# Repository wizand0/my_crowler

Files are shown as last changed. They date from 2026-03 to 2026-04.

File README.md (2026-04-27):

# 🔦 Crawler Inspector — Робот-телеинспектор вентиляции

> **Самодельный автономный краулер для осмотра вентиляционных каналов**  
> Платформа T101 · ESP32-CAM · Arduino UNO R3 · Wi-Fi управление · Автопилот · Запись видео · Лог маршрута






---

## 📸 Фотографии устройства

| | | |
|:---:|:---:|:---:|
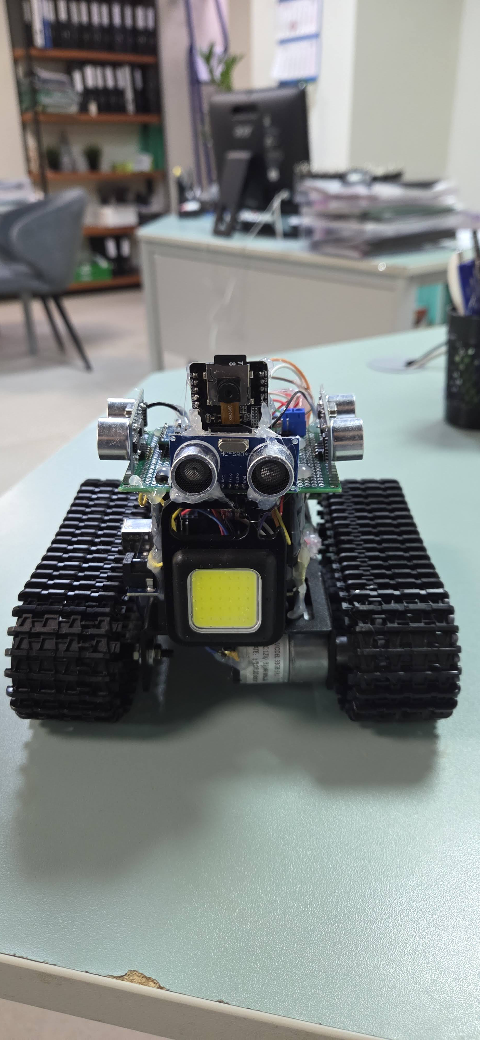
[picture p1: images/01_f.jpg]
Вид спереди
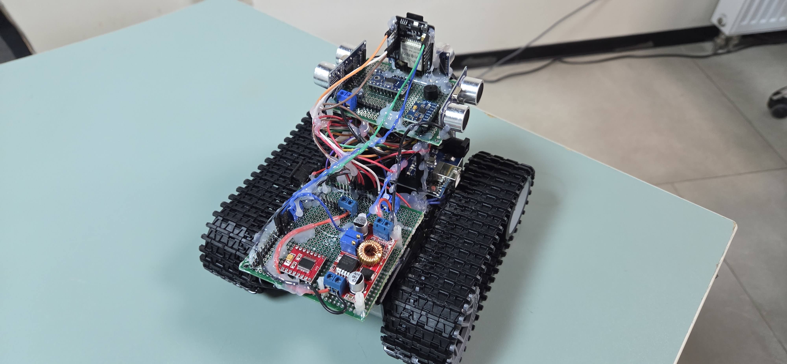
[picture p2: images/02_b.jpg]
Вид сзади
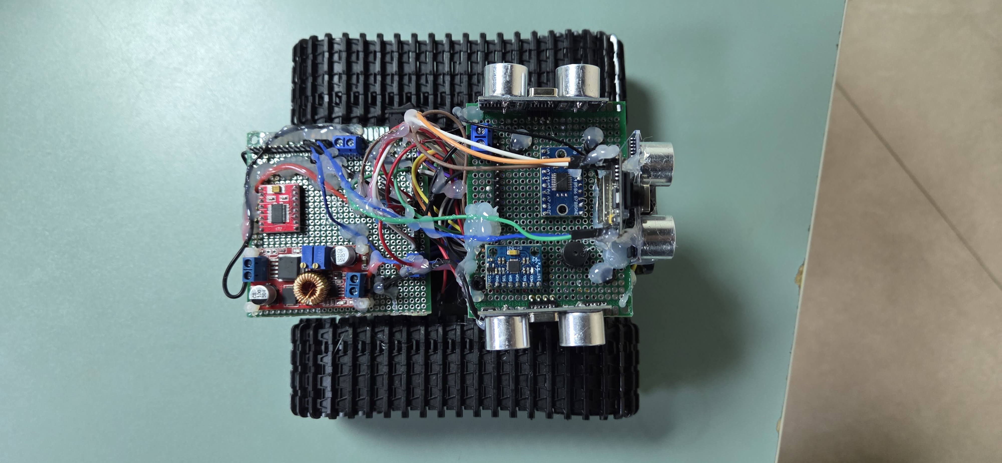
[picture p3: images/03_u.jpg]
Вид сверху
|  |  |  |
| *Вид спереди* | *Вид сзади* | *Вид сверху* |
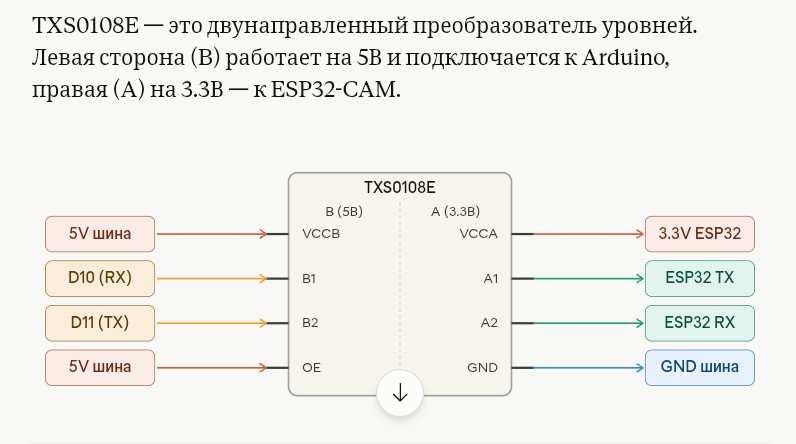
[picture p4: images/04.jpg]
Вид снизу
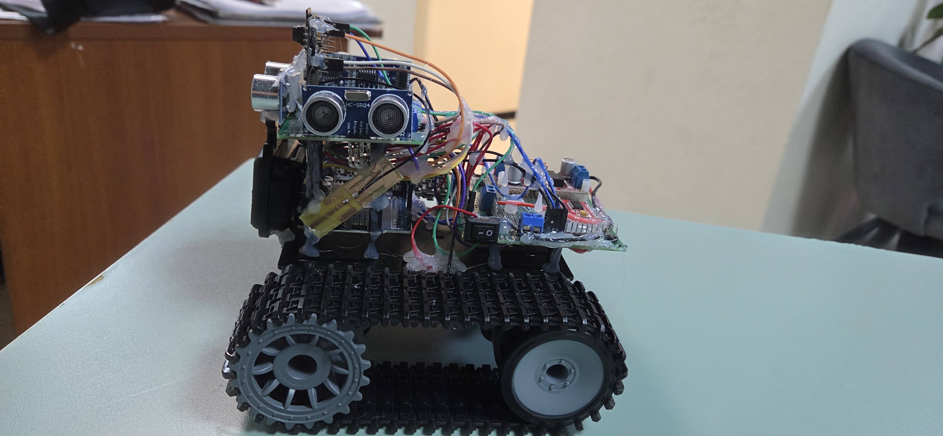
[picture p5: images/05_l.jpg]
Левый борт
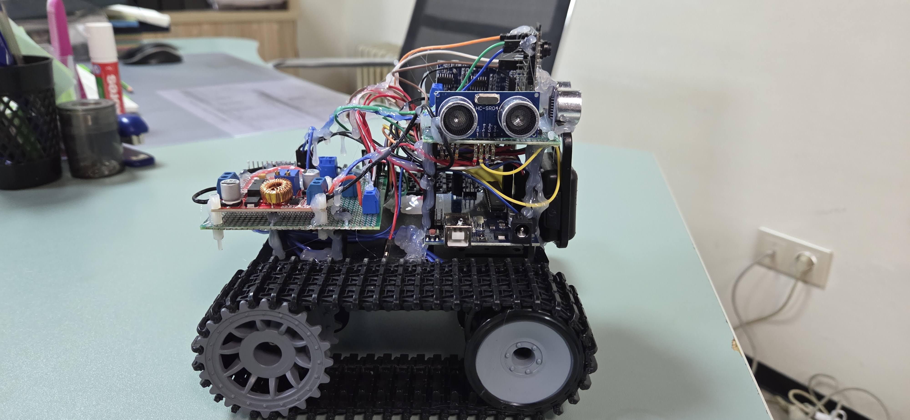
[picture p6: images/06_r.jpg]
Правый борт
|  |  |  |
| *Вид снизу* | *Левый борт* | *Правый борт* |
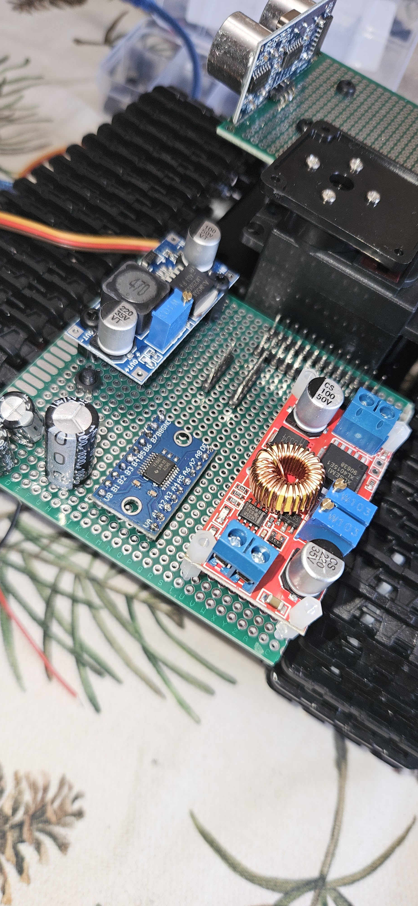
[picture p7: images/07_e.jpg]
Электроника
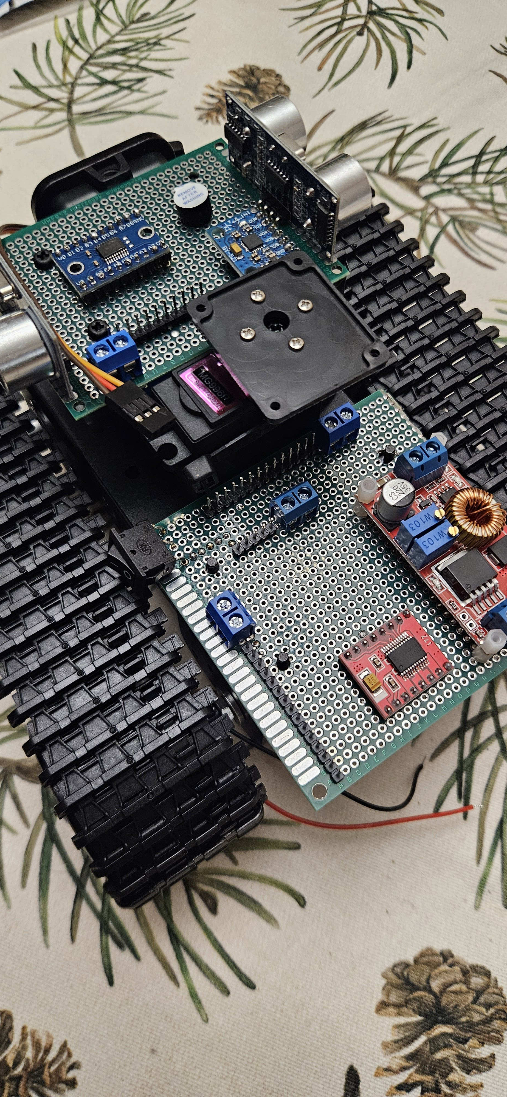
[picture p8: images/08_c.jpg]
Камера и серво
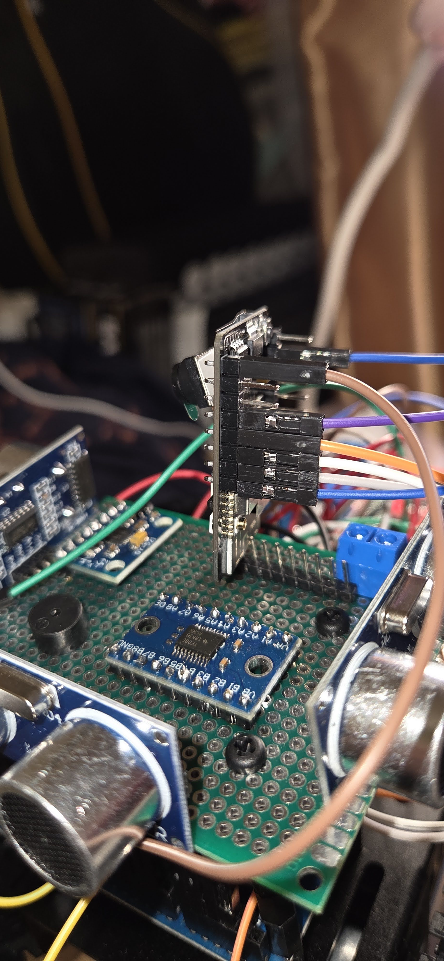
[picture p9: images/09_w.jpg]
В работе
|  |  |  |
| *Электроника* | *Камера и серво* | *В работе* |

---

## 📋 Содержание

1. [О проекте](#о-проекте)
2. [Архитектура системы](#архитектура-системы)
3. [Список компонентов](#список-компонентов)
4. [Схема подключений](#схема-подключений)
5. [Сборка шасси Mini T101](#сборка-шасси-mini-t101)
6. [Монтаж электроники](#монтаж-электроники)
7. [Пайка и коммутация](#пайка-и-коммутация)
8. [Загрузка прошивки](#загрузка-прошивки)
9. [Калибровка](#калибровка)
10. [Первое включение и тестирование](#первое-включение-и-тестирование)
11. [Веб-интерфейс управления](#веб-интерфейс-управления)
12. [Автопилот и конечный автомат](#автопилот-и-конечный-автомат)
13. [Защита от спуска](#защита-от-спуска)
14. [Одометрия и лог маршрута CSV](#одометрия-и-лог-маршрута-csv)
15. [Конвертация записи в видео](#конвертация-записи-в-видео)
16. [Зуммер-сигнализация](#зуммер-сигнализация)
17. [Описание прошивки Arduino](#описание-прошивки-arduino)
18. [Описание прошивки ESP32-CAM](#описание-прошивки-esp32-cam)
19. [Диагностика неисправностей](#диагностика-неисправностей)
20. [Конфигурационные параметры](#конфигурационные-параметры)
21. [Структура репозитория](#структура-репозитория)
22. [Зависимости и библиотеки](#зависимости-и-библиотеки)
23. [История версий (CHANGELOG)](#история-версий-changelog)
24. [Лицензия и вклад в проект](#лицензия-и-вклад-в-проект)

---

## 🤖 О проекте

**Crawler Inspector** — это самодельный робот-телеинспектор, предназначенный для видеоосмотра вентиляционных каналов и других труднодоступных пространств. Основная задача — заменить ручную инспекцию вентиляции в жилых и промышленных зданиях без дорогостоящего профессионального оборудования.

Оператор управляет роботом через браузер (смартфон или ноутбук) по Wi-Fi, видя прямую трансляцию с камеры. При потере сигнала или нажатии AUTO робот самостоятельно продолжает движение до 20 минут, логируя маршрут в CSV-файл. На конце страховочного троса оператор физически вытягивает краулер.

### Ключевые возможности v2.0

| Возможность | Описание |
|---|---|
| **Wi-Fi управление** | Браузерный интерфейс с джойстиком, работает на смартфоне и ноутбуке |
| **MJPEG видеопоток** | Прямая трансляция с камеры OV2640 (320×240 или 640×480) |
| **Автономный автопилот** | Автоматическая езда по коридору с огибанием препятствий |
| **PTZ-камера** | Поворот камеры 45–135° сервоприводом MG996R |
| **Запись на SD** | Автостарт сохранения JPEG-кадров (5 fps) при включении |
| **Защита от спуска** | Обнаружение наклона >30° через MPU6050, аварийная остановка |
| **Лог маршрута CSV** | Одометрия, накопленное рыскание, события, показания датчиков |
| **Зуммер-сигнализация** | Паттерны SOS, BEACON, CRAWL, ABANDONED для разных ситуаций |
| **JSON /status API** | Эндпоинт статуса для внешних систем мониторинга |

### Сценарий применения

Краулер предназначен для работы с крыш и верхних точек зданий, где вентиляционные каналы уходят вниз. Оператор управляет роботом вручную, пока есть Wi-Fi сигнал (обычно 3–4 метра в металлическом коробе), затем робот автоматически переходит в режим автопилота и продолжает движение самостоятельно. По окончании маршрута или при обнаружении тупика / спуска подаётся сигнал зуммером. Оператор вытягивает робота за страховочный трос, прикреплённый к шасси. На SD-карте остаются видеокадры и CSV-лог с картой маршрута.

---

## 🏗 Архитектура системы

```
╔══════════════════════════════════════════════════════════════════════════╗
║                          CRAWLER INSPECTOR v2.0                          ║
║                                                                          ║
║  ┌──────────────────────┐  UART 9600 бод  ┌──────────────────────────┐   ║
║  │    ESP32-CAM          │◄──────────────►│    Arduino UNO R3        │   ║
║  │    (Master)           │   TXS0108E     │    (Slave)               │   ║
║  │                       │   3.3V ↔ 5V    │                          │   ║
║  │  • Wi-Fi AP           │                │  • TB6612FNG (моторы)    │   ║
║  │  • Веб-сервер :80    │ F,B,L,R,S,P,H   │  • HC-SR04 × 3           │   ║
║  │  • MJPEG :81         │◄───────────────►│  • MPU6050 (pitch+yaw)   │   ║
║  │  • SD-карта (запись) │  LOG:EVT,...    │  • Servo MG996R          │   ║
║  │  • CSV лог маршрута  │  REC_AUTO       │  • Зуммер                │   ║
║  └──────────────────────┘                 └──────────────────────────┘   ║
╚══════════════════════════════════════════════════════════════════════════╝
```

**Ролевое разделение:**

- **ESP32-CAM (Master)** — управляет Wi-Fi, стримингом видео, записью на SD, CSV-логом маршрута. Отправляет команды на Arduino и принимает LOG-строки.
- **Arduino UNO (Slave)** — управляет моторами, ультразвуковыми датчиками, IMU, сервоприводом и зуммером. Выполняет всю логику конечного автомата.

---

## 🛒 Список компонентов

| Компонент | Кол-во | Назначение |
|---|:---:|---|
| Шасси Mini T101 (гусеничное) | 1 | Платформа робота |
| ESP32-CAM AI-Thinker | 1 | Мастер: Wi-Fi, камера, SD |
| Arduino UNO R3 | 1 | Слейв: управление периферией |
| TB6612FNG (модуль) | 1 | Драйвер двух моторов |
| Моторы 33GB-520 (под T101) | 2 | Привод гусениц |
| HC-SR04 | 3 | УЗ-дальномеры (перед, лево, право) |
| MPU6050 | 1 | Акселерометр + гироскоп (pitch/yaw) |
| Servo MG996R | 1 | Поворот камеры 0–180° |
| TXS0108E (модуль) | 1 | Согласование уровней 3.3V / 5V |
| MicroSD-карта FAT32 (≤32 ГБ) | 1 | Запись JPEG + CSV лог |
| Преобразователь XL4015 | 1 | Step-down до 5.0 В |
| Аккумулятор LiPo 2S (или 3S) | 1 | Питание |
| Зуммер пассивный 5 В | 1 | Звуковая сигнализация |
| MB-плата для ESP32-CAM | 1 | Загрузка прошивки |
| Нейлоновые стойки M3 | 8 | Крепление плат |
| Страховочный трос | 1 | Извлечение робота (обязательно!) |

---

## 🔌 Схема подключений

### Arduino UNO R3 (актуальная распиновка v2.0)

> ⚠️ В коде v2.0 распиновка моторов **изменена** относительно заголовочного комментария. Актуальные значения из `#define`:

| Пин Arduino | Функция | Комментарий |
|---|---|---|
| **D2** | Servo MG996R (сигнал) | Поворот камеры |
| **D3** | TB6612 BIN2 (мотор B) | |
| **D4** | TB6612 BIN1 (мотор B) | |
| **D5** | TB6612 PWMB (мотор B) | ШИМ правого мотора |
| **D6** | TB6612 PWMA (мотор A) | ШИМ левого мотора |
| **D7** | TB6612 AIN1 (мотор A) | |
| **D8** | TB6612 AIN2 (мотор A) | |
| **D9** | Зуммер (пассивный) | `tone()` 2000 Гц |
| **D10** | SoftwareSerial RX ← TXS0108E | Приём от ESP32 |
| **D11** | SoftwareSerial TX → TXS0108E | Отправка на ESP32 |
| **D12** | HC-SR04 RIGHT TRIG | УЗ правый |
| **D13** | HC-SR04 RIGHT ECHO | УЗ правый |
| **A0** | HC-SR04 FRONT TRIG | УЗ передний |
| **A1** | HC-SR04 FRONT ECHO | УЗ передний |
| **A2** | HC-SR04 LEFT TRIG | УЗ левый |
| **A3** | HC-SR04 LEFT ECHO | УЗ левый |
| **A4 (SDA)** | MPU6050 SDA | I2C, адрес 0x68 |
| **A5 (SCL)** | MPU6050 SCL | I2C |
| **5V** | TB6612 STBY | Всегда включён |

### ESP32-CAM (UART к TXS0108E)

| ESP32-CAM GPIO | Направление | TXS0108E | Arduino |
|---|---|---|---|
| GPIO1 (TX0) | → | A1 → B1 | D10 (RX) |
| GPIO3 (RX0) | ← | A2 ← B2 | D11 (TX) |
| 3.3V | | VCCA + OE | |
| GND | | GND | GND |

> **Питание TXS0108E:** VCCA = 3.3V (от ESP32), VCCB = 5V (от Arduino), OE = 3.3V.

### Схемы пайки

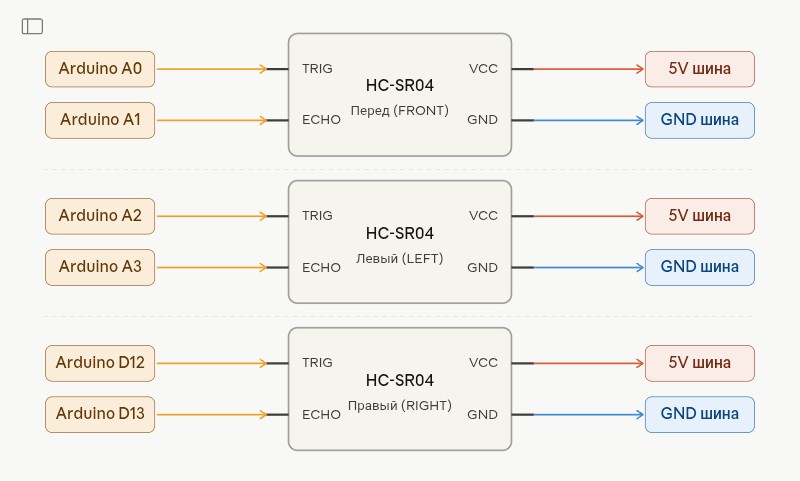
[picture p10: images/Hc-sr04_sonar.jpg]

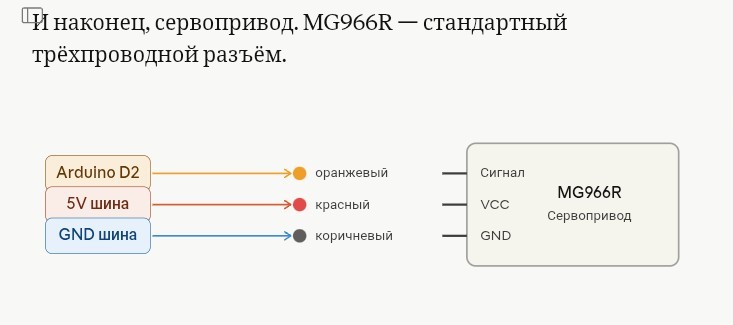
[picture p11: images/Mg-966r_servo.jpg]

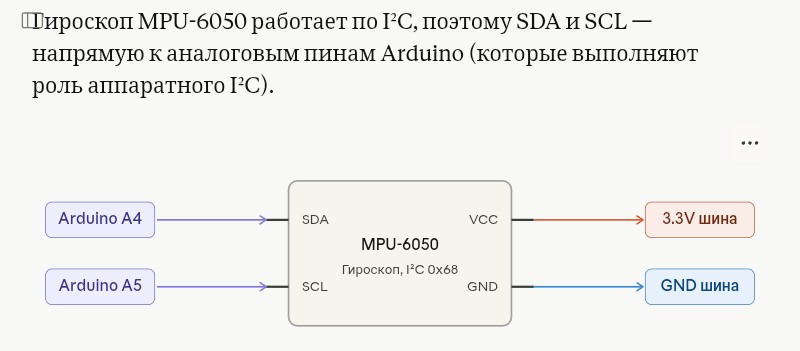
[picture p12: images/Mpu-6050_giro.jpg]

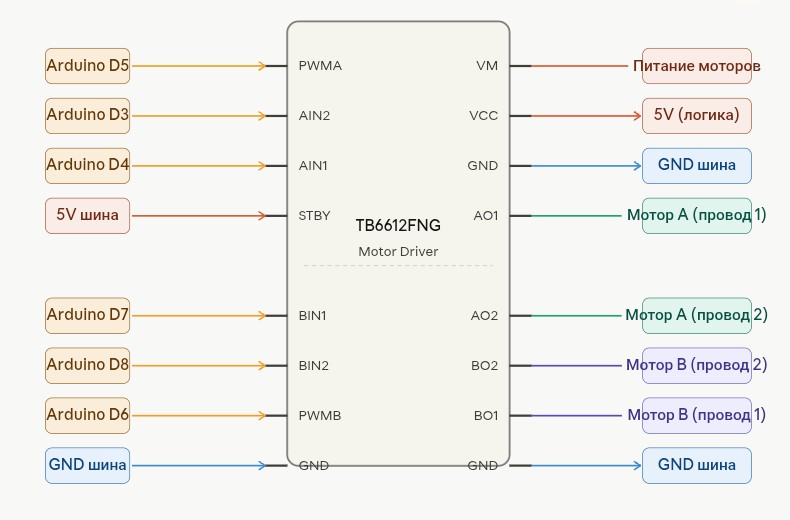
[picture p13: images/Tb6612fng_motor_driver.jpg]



---

## 🔧 Сборка шасси Mini T101

1. Собери шасси T101 с моторами 33GB-520 по инструкции производителя
2. Установи нейлоновые стойки M3 на монтажную плату
3. Закрепи TB6612FNG на стойках над корпусом
4. Размести Arduino UNO под основной платой
5. Установи ESP32-CAM на сервоплатформу спереди
6. Закрепи MG996R для поворота камеры (угол 45–135°)
7. Прикрути три HC-SR04: спереди по центру, слева, справа
8. Закрепи MPU6050 горизонтально по оси движения робота

---

## ⚡ Монтаж электроники

1. Настрой XL4015 на выходное напряжение **5.00 В** мультиметром до подключения нагрузки
2. Припаяй шины питания: 5V и GND на монтажной плате
3. Подключи TB6612FNG к Arduino согласно таблице выше
4. Подключи TXS0108E между ESP32 и Arduino
5. Подключи три HC-SR04 к Arduino
6. Подключи MPU6050 по I2C (A4/A5)
7. Подключи серво MG996R к D2 и 5V
8. Подключи зуммер к D9 и GND
9. Вставь SD-карту (FAT32, ≤32 ГБ) в ESP32-CAM

---

## 🛠 Загрузка прошивки

### Arduino UNO

```
1. Открой Arduino_UNO_Slave_v5.ino в Arduino IDE
2. Плата: Tools → Board → Arduino UNO
3. Порт: выбери COM-порт Arduino
4. Загрузи (Ctrl+U)
```

### ESP32-CAM

> ⚠️ **После загрузки через MB-плату: отключи USB-кабель перед подключением Arduino к UART. Иначе Arduino будет принимать USB-мусор вместо команд.**

```
1. Открой ESP32_CAM_Master_v5.ino в Arduino IDE
2. Установи пакет: Tools → Board Manager → "ESP32 by Espressif Systems" ≥ 2.0
3. Плата: AI-Thinker ESP32-CAM
4. Подключи MB-плату, переведи ESP32 в режим загрузки (IO0 → GND)
5. Загрузи, затем нажми кнопку Reset на ESP32-CAM
6. Отключи USB-кабель MB-платы
7. Подключи провода UART к Arduino
```

---

## 📐 Калибровка

### SPEED_MPS — одометрия (обязательно!)

Скорость `SPEED_MPS` используется для расчёта пройденного расстояния в одометрии и CSV-логе маршрута. Некалиброванное значение даст неточный лог.

```
1. Поставь краулер на ровную поверхность
2. Отметь стартовую точку маркером
3. Включи питание, подключись к Wi-Fi Crawler_Inspector
4. Нажми F (вперёд) и засеки точное время до 1 метра
5. SPEED_MPS = 1.0 / время_в_секундах
   Пример: проехал 1 м за 4.0 с → SPEED_MPS = 0.25f  (уже настроено)
6. Обнови значение в Arduino_UNO_Slave_v5.ino и перезагрузи
```

### Балансировка моторов

Если робот ведёт в сторону при движении вперёд, откорректируй масштаб мотора:

```cpp
#define MOTOR_L_SCALE   1.00f   // левый мотор (не трогать)
#define MOTOR_R_SCALE   0.90f   // уменьши, если правый быстрее
```

---

## ▶️ Первое включение и тестирование

```
1. Вставь SD-карту (FAT32, ≤32 ГБ) в ESP32-CAM
2. Прикрепи страховочный трос к шасси (обязательно!)
3. Включи питание — зуммер даст 2 пика (самотест OK)
4. Подожди 3–4 секунды инициализации
5. Подключись к Wi-Fi: "Crawler_Inspector" / "crawler123"
6. Открой браузер: http://192.168.4.1
7. Убедись что видеопоток запустился (статус 🟢 Видео: ОК)
8. Проверь что надпись "● REC" мигает (автозапись активна)
9. Протестируй движение джойстиком в ручном режиме
10. Откалибруй SPEED_MPS по реальному замеру (см. выше)
```

---

## 🌐 Веб-интерфейс управления

**Адрес:** `http://192.168.4.1` (порт 80)  
**Видеопоток:** `http://192.168.4.1:81/stream` (MJPEG)

### Элементы интерфейса

| Элемент | Функция |
|---|---|
| Видеоокно | MJPEG-поток с камеры OV2640 |
| Джойстик (canvas) | Управление направлением: F / B / L / R / S |
| Слайдер камеры | Поворот сервопривода 0–180° (команда `P<угол>`) |
| Кнопка ● REC | Ручное включение/выключение записи на SD |
| Кнопка AUTO | Включить/выключить режим автопилота |
| Статус | Текущее состояние: MANUAL / AUTO / REC_AUTO / AUTO_NO_WIFI |
| Пинг | Время отклика до ESP32 |
| Лог маршрута | Последняя строка из route_log.csv |

### HTTP API

| Метод | Путь | Параметры | Описание |
|---|---|---|---|
| GET | `/` | — | Главная страница (HTML/JS) |
| GET | `/cmd` | `m=F/B/L/R/S` или `p=<0-180>` | Команда мотора или угол серво |
| GET | `/rec` | `start=1/0` | Вкл/выкл запись на SD |
| GET | `/ping` | — | Ответ `pong` |
| GET | `/status` | — | JSON: состояние, последний лог |
| POST | `/auto` | `{"auto":true/false}` | Вкл/выкл автопилот |

#### Пример `/status` ответа

```json
{
  "status": "AUTO",
  "recording": true,
  "sd_ok": true,
  "session": "/REC_3",
  "last_log": "LOG:CHK,142,15,8,45,210,38",
  "clients": 1
}
```

---

## 🤖 Автопилот и конечный автомат

Автопилот включается автоматически при:
- Нажатии кнопки **AUTO** в интерфейсе
- Потере Wi-Fi клиента (нет heartbeat > 3 секунд)
- Приходе команды `'A'` от ESP32 (клиент отключился)

Максимальное время автономной миссии: **20 минут** (AUTO_MISSION_TIME).

### Состояния конечного автомата

```
                    ┌─────────────────────────────┐
                    │          ST_MANUAL          │
                    │  (оператор управляет)       │
                    └───────────────┬─────────────┘
                   AUTO / потеря HB │
                                    ▼
                    ┌──────────────────────────────┐
              ┌────►│        ST_AUTO_FWD           │◄───────┐
              │     │  едем вперёд, объезжаем      │        │
              │     └──┬──────────────┬────────────┘        │
              │     нет│ места        │тупик                │
              │        ▼              ▼                     │
              │  ┌─────────────┐  ┌─────────────┐           │
              │  │ST_AUTO_     │  │ ST_AUTO_    │           │
              │  │REVERSE      │  │ DEAD        │           │
              │  │(реверс 350мс│  │(зуммер SOS) │           │
              │  └──────┬──────┘  └─────────────┘           │
              │         ▼                                   │
              │  ┌──────────────────────────────┐           │
              └──┤        ST_AUTO_TURN          ├───────────┘
                 │  (поворот влево / вправо)    │
                 └──────────────────────────────┘
                              │ наклон > 30°
                              ▼
                 ┌────────────────────────────────┐
                 │        ST_TILT_PAUSE           │
                 │  (стоп, зуммер 8 сек)          │
                 └───────────────┬────────────────┘
                                 │ попытка движения
                                 ▼
                 ┌────────────────────────────────┐
                 │      ST_TILT_TRY_MOVE          │
                 │  (900 мс, скорость 65)         │
                 └────────────────────────────────┘
```

### Параметры автопилота

| Параметр | Значение | Описание |
|---|---|---|
| `SPEED_AUTO` | 55 | Базовая скорость в автопилоте |
| `SPEED_AUTO_MIN` | 42 | Минимум в тесных местах |
| `SPEED_AUTO_MAX` | 95 | Максимум на свободном участке |
| `DIST_FRONT_STOP` | 15 см | Стоп и разворот |
| `DIST_FRONT_CLEAR` | 24 см | Путь свободен |
| `DIST_SIDE_DEAD` | 12 см | Опасное сближение со стенкой |
| `DIST_SIDE_WARN` | 18 см | Предупреждение, корректировка курса |
| `TURN_FAIL_LIMIT` | 5 | Неудачных разворотов подряд → тупик |
| `OBSTACLE_MEMORY_MS` | 12000 мс | Окно памяти одного препятствия |
| `REVERSE_BEFORE_TURN_MS` | 350 мс | Реверс перед разворотом |

---

## ⛰ Защита от спуска

**Абсолютный приоритет** — выполняется первой в каждом цикле loop при любом состоянии кроме ST_MANUAL.

```
pitch < -30°  →  ST_TILT_PAUSE (стоп + непрерывный зуммер, 8 сек)
                 → ST_TILT_TRY_MOVE (попытка выехать, 900 мс, скорость 65)
                    → pitch > -10°  →  возврат в ST_AUTO_FWD
                    → pitch ≤ -10°  →  снова ST_TILT_PAUSE
                       (до 255 попыток)
```

**Фильтр наклона** предотвращает ложные срабатывания от вибрации:
- Требует **5 подряд** плохих измерений (`TILT_CONFIRM_COUNT`)
- Наклон должен держаться минимум **200 мс** (`TILT_CONFIRM_MS`)
- Для выхода из тревоги — **5 подряд** хороших измерений (`TILT_RELEASE_COUNT`)

> ⚠️ **Всегда прикрепляй страховочный трос к шасси!** При срабатывании защиты оператор должен удержать трос — это ключевой элемент безопасной эксплуатации.

---

## 📊 Одометрия и лог маршрута CSV

### Принцип работы

Arduino рассчитывает пройденное расстояние на основе времени движения и скорости `SPEED_MPS`. Рыскание (yaw) накапливается из гироскопа gz MPU6050.

При наступлении триггера формируется строка лога и отправляется по UART на ESP32, который записывает её в `/route_log.csv` на SD-карте.

### Триггеры записи в лог

| Событие | Код | Триггер |
|---|---|---|
| Контрольная точка | `CHK` | Каждые 0.5 м пути |
| Поворот | `TURN` | Накоплено > 20° рыскания |
| Наклон (спуск) | `TILT` | pitch < −30° |
| Восстановление | `TRES` | Выход из ST_TILT_PAUSE |
| Препятствие | `OBS` | Объезд в автопилоте |
| Тупик | `DEAD` | 5 неудачных разворотов |
| Потеря сигнала | `WLOST` | Нет heartbeat > 3 сек |
| Сигнал вернулся | `WOK` | Heartbeat получен снова |
| Старт автопилота | `ASTART` | Переход из ST_MANUAL |
| Конец автопилота | `AEND` | Таймаут 20 мин или ручной стоп |

### Формат CSV-строки

```
LOG:<EVT>,<dist_cm>,<yaw_x10>,<pitch_x10>,<dF>,<dL>,<dR>
```

| Поле | Единица | Описание |
|---|---|---|
| EVT | — | Код события (CHK, TURN, ...) |
| dist_cm | сантиметры | Пройденное расстояние |
| yaw_x10 | градусы × 10 | Накопленный поворот с прошлой записи |
| pitch_x10 | градусы × 10 | Текущий тангаж |
| dF | сантиметры | Дистанция вперёд (HC-SR04) |
| dL | сантиметры | Дистанция влево |
| dR | сантиметры | Дистанция вправо |

**Пример:**
```csv
LOG:ASTART,0,0,2,180,180,180
LOG:CHK,50,15,3,62,38,210
LOG:TURN,87,-215,5,45,38,71
LOG:OBS,112,-23,4,14,210,38
LOG:TILT,124,0,-312,18,210,210
```

---

## 🎬 Конвертация записи в видео

Кадры сохраняются в папку `/REC_<n>/` на SD-карте в формате JPEG (5 fps).

```bash
# Установи ffmpeg если не установлен
# Windows: winget install ffmpeg
# macOS:   brew install ffmpeg
# Linux:   sudo apt install ffmpeg

# Конвертация папки JPEG → MP4
ffmpeg -framerate 5 -i /путь/к/REC_1/frame_%05d.jpg \
       -c:v libx264 -pix_fmt yuv420p \
       output.mp4
```

---

## 🔔 Зуммер-сигнализация

| Паттерн | Ситуация | Звук |
|---|---|---|
| **BEACON** | Старт автопилота, выход из тревоги | 1 короткий пик (100 мс) |
| **SOS** | *(зарезервировано)* | Морзе: · · · — — — · · · |
| **ABANDONED** | Автомиссия завершена (20 мин) | Долгий гудок 500 мс каждые 20 сек |
| **CONTINUOUS** | Активная тревога наклона (ST_TILT_PAUSE) | Непрерывный тон 2000 Гц |
| **2 пика при старте** | Самотест завершён успешно | Тон 1500 Гц + 2500 Гц |

---

## 📄 Описание прошивки Arduino

**Файл:** `Arduino_UNO_Slave_v5.ino` (прошивка v2.0)

### Главный цикл `loop()` — 8 задач без `delay()`

```
1. uartRead()          — приём команд F/B/L/R/S/P/H/A от ESP32
2. mpuUpdate()         — обновление pitch + gyroZ каждые 20 мс
3. medDist()           — поочерёдный опрос 3 HC-SR04 каждые ~83 мс
4. checkTilt()         — [ПРИОРИТЕТ] проверка наклона (всегда первой)
5. updateOdometry()    — расчёт расстояния + накопление yaw + триггеры лога
6. failsafe            — контроль heartbeat, переключение режимов
7. Конечный автомат    — handleManual/AutoFwd/AutoReverse/AutoTurn/...
8. buzzUpdate()        — неблокирующий вывод паттернов зуммера
```

### Протокол UART

**ESP32 → Arduino:**
```
'F'          — вперёд
'B'          — назад
'L'          — налево
'R'          — направо
'S'          — стоп
'P<угол>\n'  — установить угол серво (0–180)
'H'          — heartbeat (каждые 500 мс, клиент подключён)
'A'          — autopilot (клиент отключился, перейти в автопилот)
```

**Arduino → ESP32:**
```
'REC_AUTO\n'                        — запрос автозапуска записи (при старте)
'LOG:EVT,dist,yaw,pitch,dF,dL,dR\n' — событие маршрута для CSV
```

### Complementary-фильтр IMU

Тангаж вычисляется с весом 98% гироскопа и 2% акселерометра:
```cpp
pitch = 0.98f * (pitch + gRate * dt) + 0.02f * aPitch;
```
Оси MPU6050 программно переориентированы под физическое положение датчика.

### Медианный фильтр HC-SR04

Каждый HC-SR04 опрашивается 3 раза подряд, возвращается медиана. Это устраняет единичные ложные показания. Датчики опрашиваются поочерёдно (не одновременно) во избежание акустических помех.

---

## 📷 Описание прошивки ESP32-CAM

**Файл:** `ESP32_CAM_Master_v5.ino` (прошивка v2.0)

### Автостарт записи

При включении ESP32 сразу запускает сессию записи (если SD-карта инициализирована), не дожидаясь команды оператора. При отключении клиента запись продолжается автоматически.

### Retry инициализации SD

Если SD-карта не определилась при старте, ESP32 повторяет попытку каждые 5 секунд. При успехе автоматически запускает новую сессию записи.

### Управление heartbeat

- Пока клиент подключён по Wi-Fi → отправляет `'H'` каждые 500 мс
- Когда клиент отключился → отправляет `'A'` (Arduino переходит в автопилот)
- Arduino имеет таймаут 3 секунды — если `'H'` не пришёл, переходит в автопилот самостоятельно

### Передача мощности Wi-Fi

```cpp
WiFi.setTxPower(WIFI_POWER_19_5dBm);  // максимум 19.5 dBm (по умолчанию 17)
```
Увеличенная мощность расширяет дальность связи в металлических воздуховодах.

---

## 🔍 Диагностика неисправностей

| Симптом | Вероятная причина | Решение |
|---|---|---|
| Нет Wi-Fi "Crawler_Inspector" | ESP32 не запустился | Проверь питание 5V, нажми Reset |
| Видео не идёт | Поток :81 не запустился | Перезагрузи ESP32, проверь камеру |
| Нет REC-иконки | SD не определилась | Проверь FAT32, ≤32 ГБ, вставлена? |
| Робот не едет | Arduino не получает команды | Проверь UART-провода, TXS0108E |
| Едет в сторону | Разбаланс моторов | Уменьши `MOTOR_R_SCALE` |
| Срабатывает защита спуска | MPU6050 некорректно установлен | Проверь ориентацию, перекалибруй |
| Нет звука самотеста | Зуммер не подключён к D9 | Проверь пайку |
| CSV-лог пустой | `REC_AUTO` не получен | Убедись что heartbeat приходит |
| Робот не переходит в AUTO | Heartbeat всё ещё идёт | Отключи Wi-Fi на телефоне |

---

## ⚙️ Конфигурационные параметры

### Arduino UNO (Arduino_UNO_Slave_v5.ino)

```cpp
// ── Скорости ──────────────────────────────────────────────
#define SPEED_FULL       200    // максимальная скорость (PWM)
#define SPEED_SLOW        76    // медленная скорость
#define SPEED_AUTO        55    // базовая автопилота
#define SPEED_AUTO_MIN    42    // минимум в тесных местах
#define SPEED_AUTO_MAX    95    // максимум на свободных участках

// ── Дистанции (см) ────────────────────────────────────────
#define DIST_FRONT_STOP   15    // стоп, разворот
#define DIST_FRONT_CLEAR  24    // путь свободен
#define DIST_SIDE_DEAD    12    // критическое сближение со стенкой
#define DIST_SIDE_WARN    18    // предупреждение, корректировка

// ── Защита от спуска ──────────────────────────────────────
#define DESCENT_TRIG    -30.0f  // порог тревоги (градусы)
#define RECOVERY_TRIG   -10.0f  // порог выхода из тревоги

// ── Одометрия ─────────────────────────────────────────────
#define SPEED_MPS       0.25f   // м/с при SPEED_FULL (откалибруй!)
#define CHECKPOINT_DIST  0.50f  // лог каждые N метров
#define MIN_LOG_TURN    20.0f   // лог поворота при накоплении > N°

// ── Таймауты ──────────────────────────────────────────────
#define AUTO_MISSION_TIME 1200000UL  // 20 мин автопилота
#define MANUAL_FAILSAFE_TIMEOUT 3000UL // потеря heartbeat → AUTO
#define TILT_PAUSE_MS     8000UL      // пауза при наклоне
#define TILT_TRY_MOVE_MS   900UL      // попытка выехать
```

### ESP32-CAM (ESP32_CAM_Master_v5.ino)

```cpp
const char* AP_SSID = "Crawler_Inspector";  // имя Wi-Fi сети
const char* AP_PASS = "crawler123";          // пароль Wi-Fi
// IP: 192.168.4.1 (фиксированный)

#define UART_BAUD       9600   // скорость UART с Arduino
#define HEARTBEAT_MS     500   // период heartbeat 'H' → Arduino
#define FRAME_SAVE_MS    200   // период сохранения кадра (5 fps)
#define CMD_REPEAT_MS    120   // период повтора команды мотора
```

---

## 📁 Структура репозитория

```
crawler-inspector/
├── Arduino_UNO_Slave_v5.ino     # Прошивка Arduino UNO (v2.0)
├── ESP32_CAM_Master_v5.ino      # Прошивка ESP32-CAM (v2.0)
├── README.md                    # Этот файл
├── CHANGELOG.md                 # История изменений
├── LICENSE                      # MIT License
└── images/                      # Фотографии устройства
    ├── 01.jpg                   # Вид спереди
    ├── 02.jpg                   # Вид сзади
    ├── 03.jpg                   # Вид сверху
    ├── 04.jpg                   # Вид снизу
    ├── 05.jpg                   # Левый борт
    ├── 06.jpg                   # Правый борт
    ├── 07.jpg                   # Электроника
    ├── 08.jpg                   # Камера и серво
    └── 09.jpg                   # В работе
```

---

## 📦 Зависимости и библиотеки

### Arduino UNO

| Библиотека | Источник | Назначение |
|---|---|---|
| `SoftwareSerial.h` | Встроена в Arduino IDE | UART с ESP32 на D10/D11 |
| `Servo.h` | Встроена в Arduino IDE | Управление MG996R |
| `Wire.h` | Встроена в Arduino IDE | I2C для MPU6050 |

### ESP32-CAM

| Библиотека / пакет | Источник | Назначение |
|---|---|---|
| `ESP32 by Espressif Systems` ≥ 2.0 | Arduino Boards Manager | Поддержка ESP32 |
| `esp_camera.h` | В составе ESP32 пакета | Драйвер камеры OV2640 |
| `esp_http_server.h` | В составе ESP32 пакета | Веб-сервер |
| `SD_MMC.h` | В составе ESP32 пакета | SD-карта через MMC |
| `WiFi.h` | В составе ESP32 пакета | Wi-Fi точка доступа |

---

## 📝 История версий (CHANGELOG)

### v2.0 (2026-03-21)

**Добавлено:**
- Одометрия по времени с компенсацией ШИМ (`SPEED_MPS`)
- Вычисление рыскания (yaw) через gz гироскопа MPU6050
- Событийное логирование маршрута (10 типов событий, формат CSV)
- Запись `route_log.csv` на SD-карту через ESP32
- Автостарт записи видео при включении (без нажатия REC)
- Команда `REC_AUTO` от Arduino к ESP32 при первом heartbeat
- Эндпоинт `/status` с JSON-статусом краулера
- Строка последнего лог-события в веб-интерфейсе
- Входящий UART-буфер 128 байт на ESP32 (чтение LOG-строк)
- Кнопка AUTO в веб-интерфейсе

**Изменено:**
- `setMotors()` теперь сохраняет `leftSpeed`/`rightSpeed` для одометрии
- `mpuUpdate()` теперь также читает gz (рыскание)
- `handleManual()` логирует препятствия через `logEvent(EVT_OBSTACLE)`
- `checkDescent()` логирует начало и конец спуска
- Исправлена распиновка TB6612FNG (PWMA↔PWMB переставлены)
- Переработан failsafe: потеря heartbeat → автономная миссия (не стоп)

### v1.0 (2026-03-20)

- Первоначальная версия
- Управление моторами, HC-SR04, MPU6050 pitch, серво, зуммер
- Wi-Fi AP, MJPEG стриминг, запись JPEG на SD
- Конечный автомат 6 состояний
- Защита от спуска (абсолютный приоритет)
- Автопилот с дифференциальным рулением

---

## 📜 Лицензия и вклад в проект

**Лицензия:** MIT — свободное использование, изменение и распространение с сохранением текста лицензии.

### Вклад в проект

Буду рад, если ты собрал этот краулер или улучшил его:

- **Pull Request** с исправлениями ошибок или новыми функциями
- **Issue** с описанием проблемы или предложением улучшения
- **Фотографии** собранного устройства (добавляй в папку `images/`)
- **Откалиброванное значение `SPEED_MPS`** для шасси T101 с указанием напряжения батареи

### Благодарности

- Сообщество **Espressif** за пакет arduino-esp32 и примеры esp32-camera
- Авторы шасси **Mini T101** за доступную платформу
- Сообщество **Arduino** за открытую экосистему библиотек

---

## ⚡ Быстрый старт (краткое резюме)

```
1.  Собери шасси T101 с моторами 33GB-520
2.  Установи нейлоновые стойки, закрепи платы
3.  Настрой XL4015 на 5.00 В мультиметром
4.  Подключи всё по схеме из README
5.  Залей ESP32_CAM_Master_v5.ino на ESP32-CAM через MB-плату
6.  Залей Arduino_UNO_Slave_v5.ino на Arduino UNO
7.  Вставь SD-карту (FAT32, ≤32 ГБ) в ESP32-CAM
8.  Прикрепи страховочный трос к шасси (обязательно!)
9.  Включи питание → 2 пика зуммера → Wi-Fi Crawler_Inspector
10. Открой http://192.168.4.1 → видео + джойстик
11. Откалибруй SPEED_MPS по реальному замеру (п. 9 README)
12. Вперёд!
```

> ⚠️ **Не запускай краулер в вентиляционный канал без страховочного троса.** При срабатывании защиты спуска оператор должен удерживать трос — это ключевой элемент безопасной эксплуатации.

---

*Проект разработан для домашнего использования. Автор не несёт ответственности за любой ущерб, связанный с использованием устройства. Всегда соблюдай технику безопасности при работе с литий-ионными аккумуляторами и электромеханическими системами.*

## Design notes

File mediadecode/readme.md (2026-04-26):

fix jpegs
```
python fix_jpegs.py C:\REC_0
```

После восстановления кадры можно склеить как описано в README:

```
PS C:\images\REC_0> ffmpeg -framerate 5 -i C:\Games\images\REC_0\%05d.jpg -c:v libx264 -pix_fmt yuv420p output.mp4
ffmpeg -framerate 5 -i C:\Games\images\REC_0\%05d.jpg -vf "hflip" -c:v libx264 -pix_fmt yuv420p output.mp4
```
Если ffmpeg жалуется на пропуски в нумерации (после удаления битых), используй с флагом -start_number:

```
ffmpeg -framerate 5 -start_number 1 -i REC_0/%05d.jpg \
       -vf "fps=5" -c:v libx264 -pix_fmt yuv420p \
       -vsync vfr output.mp4
````

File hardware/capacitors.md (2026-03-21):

Маленькие керамические конденсаторы (обычно номиналом **0.1 мкФ** или **100 нФ**) жизненно необходимы для коллекторных моторов, таких как ваши 33GB-520.

Без них искрение щеток внутри мотора создает мощные высокочастотные помехи, из-за которых:
1.  **ESP32-CAM** будет постоянно терять Wi-Fi соединение.
2.  **MPU6050** (акселерометр) будет выдавать мусорные данные или зависать по шине $I^2C$.
3.  Видеопоток будет идти с артефактами или обрываться.

Вот как их правильно установить:

### 🛠 Как правильно припаять конденсаторы

Для максимальной защиты одного конденсатора «перемычкой» между ножками часто бывает недостаточно. В идеале на каждый мотор ставится **3 конденсатора**:

1.  **Первый (обязательный):** Между «+» и «-» контактами мотора. Он гасит дифференциальные помехи.
2.  **Второй:** Между «+» контактом и металлическим корпусом мотора.
3.  **Третий:** Между «-» контактом и металлическим корпусом мотора.

<details>
<summary><b>📸 Схема и процесс пайки (нажмите, чтобы развернуть)</b></summary>

**Инструкция по шагам:**
1.  Возьмите маленькую керамику (желтые «капельки»). У них нет полярности, припаивать можно любой стороной.
2.  Зачистите небольшой участок на металлическом боку мотора (можно немного поцарапать напильником или наждачкой, чтобы припой лучше "прилип").
3.  Припаяйте один конденсатор между двумя клеммами мотора.
4.  Припаяйте еще два конденсатора так, чтобы одна их ножка была на клемме, а вторая — на корпусе мотора.

**Почему это важно именно для инспектора вентиляции?**
робот будет работать в металлическом коробе. Металл отражает все радиоволны и электромагнитные помехи обратно внутрь. Если моторы будут "шуметь", этот шум мгновенно забьет слабый сигнал Wi-Fi внутри трубы.
</details>

---

### 💡 Важные уточнения по вашей схеме

| Тип конденсатора | Где ставить | Зачем нужен |
| :--- | :--- | :--- |
| **Большие (Электролиты)** | На шине питания (5В и 11.1В) | Держат "удар" при старте моторов и рывках Сервопривода. Не дают Arduino перезагрузиться. |
| **Маленькие (Керамика)** | На каждом моторе (х3) | Гасят радиопомехи ("искры"). Защищают Wi-Fi и датчики от "глюков". |

### ⚠️ Критический совет по пайке к корпусу
Будьте осторожны: **не перегревайте корпус мотора слишком долго**. На задней крышке моторов часто стоит пластиковая вставка, которая держит щетки. Если долго греть металл паяльником, пластик может оплавиться, и мотор выйдет из строя или его начнет подклинивать. 

*   *Лайфхак:* Используйте активный флюс (например, канифоль-гель или паяльную кислоту, но потом обязательно протрите спиртом) и мощный разогретый паяльник, чтобы припаяться к корпусу за 1-2 секунды.

**Резюме:** Да, припаивайте их на обе ножки обязательно. Если есть возможность — сделайте схему с тремя конденсаторами на каждый мотор (благо у вас их 50 штук, хватит с запасом). Это обеспечит стабильную картинку с камеры даже при активном маневрировании.

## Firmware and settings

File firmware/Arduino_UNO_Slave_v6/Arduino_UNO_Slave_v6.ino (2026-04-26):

/*
 * ============================================================
 *  Arduino_UNO_Slave.ino  — v2.0
 *  Робот-телеинспектор вентиляции — Ведомый (Arduino UNO R3)
 *
 *  НОВОЕ в v2.0:
 *    • Одометрия по времени (SPEED_MPS)
 *    • Накопление рыскания (yaw) через gz гироскопа
 *    • Событийное логирование маршрута → ESP32 → SD-карта
 *      Формат: LOG:EVT,dist_m,yaw_acc,pitch,dF,dL,dR
 *    • Автостарт записи на SD при включении (команда REC_AUTO)
 *
 *  Назначение пинов:
 *  ┌──────────────────────────────────────────────────────────┐
 *  │ SoftwareSerial  RX=10, TX=11  (через TXS0108E)          │
 *  │ TB6612FNG       PWMA=5  AIN1=4  AIN2=3                  │
 *  │                 PWMB=6  BIN1=7  BIN2=8                  │
 *  │                 STBY → 5V (постоянно включён)           │
 *  │ Серводвигатель  PIN=2                                   │
 *  │ Зуммер          PIN=9                                   │
 *  │ HC-SR04 FRONT   TRIG=A0  ECHO=A1                        │
 *  │ HC-SR04 LEFT    TRIG=A2  ECHO=A3                        │
 *  │ HC-SR04 RIGHT   TRIG=12  ECHO=13                        │
 *  │ MPU6050         SDA=A4   SCL=A5  (I2C, адрес 0x68)     │
 *  └──────────────────────────────────────────────────────────┘
 *
 *  Протокол UART (9600 бод):
 *    ESP32 → Arduino:
 *      'F','B','L','R','S'  — команда мотора
 *      'P<угол>\n'          — угол сервопривода (0-180)
 *      'H'                  — хартбит каждые 500 мс
 *    Arduino → ESP32:
 *      'LOG:EVT,...\n'      — строка лога маршрута (новое v2)
 * ============================================================
 */

#include <SoftwareSerial.h>
#include <Servo.h>
#include <Wire.h>

// ============================================================
//  ПИНЫ
// ============================================================
// #define PIN_PWMA    5
// #define PIN_AIN1    4
// #define PIN_AIN2    3
// #define PIN_PWMB    6
// #define PIN_BIN1    7
// #define PIN_BIN2    8
#define SW_RX      10
#define SW_TX      11
#define PIN_PWMA    6
#define PIN_AIN1    7
#define PIN_AIN2    8
#define PIN_PWMB    5
#define PIN_BIN1    4
#define PIN_BIN2    3
#define PIN_SERVO   2
#define PIN_BUZZ    9
#define TRIG_F     A0
#define ECHO_F     A1
#define TRIG_L     A2
#define ECHO_L     A3
#define TRIG_R     12
#define ECHO_R     13
#define MPU_ADDR   0x68

// ============================================================
//  ПАРАМЕТРЫ
// ============================================================
#define BAUD_SW          9600
#define SPEED_FULL       200
#define SPEED_SLOW        76
#define SPEED_AUTO          55    // базовая скорость автопилота
#define SPEED_AUTO_MIN      42    // минимальная скорость в тесных местах
#define SPEED_AUTO_MAX      95    // максимальная скорость на свободном участке


#define DIST_FRONT_STOP     15
#define DIST_FRONT_CLEAR    24
#define DIST_SIDE_DEAD      12
#define DIST_SIDE_WARN      18

#define DESCENT_TRIG     -30.0f
#define RECOVERY_TRIG    -10.0f

#define DIST_PERIOD        250
#define IMU_PERIOD          20
#define SCAN_PERIOD        100
#define SCAN_MIN            45
#define SCAN_MAX           135
#define SCAN_STEP            5

#define BUZZ_HZ           2000
#define GYRO_Z_INVERT      -1

#define AUTO_MISSION_TIME 1200000UL   // 20 минут автономного движения
#define MANUAL_FAILSAFE_TIMEOUT 3000UL
#define TILT_PAUSE_MS        8000UL
#define TILT_TRY_MOVE_MS      900UL   // короткая попытка проехать после паузы
#define TILT_TRY_SPEED         65     // скорость короткой попытки
#define TILT_RETRY_LIMIT       20

// --- Фильтр наклона ---
#define TILT_CONFIRM_COUNT     5       // сколько подряд плохих измерений нужно
#define TILT_RELEASE_COUNT    5       // сколько подряд хороших измерений нужно
#define TILT_CONFIRM_MS      200UL     // наклон должен держаться минимум столько

// --- Реверс перед разворотом ---
#define REVERSE_BEFORE_TURN_MS 350UL
#define REVERSE_SPEED           70

// --- Память препятствия / застревания ---
#define TURN_FAIL_LIMIT          5    // сколько неудачных разворотов подряд считаем тупиком
#define OBSTACLE_MEMORY_MS    12000UL // окно памяти одного и того же препятствия

#define MOTOR_L_INVERT        -1
#define MOTOR_R_INVERT        -1
#define MOTOR_L_SCALE       1.00f
#define MOTOR_R_SCALE       0.90f

unsigned long lastCmdTime = 0;
#define CMD_TIMEOUT 400   // мс

// --- Верификация тупика (НОВОЕ) ---
#define DEAD_VERIFY_BACK_MS    500UL   // отъезд назад перед разворотом
#define DEAD_VERIFY_BACK_SPD    70     // скорость отъезда
#define DEAD_ROTATE_YAW        170.0f  // целевой угол разворота (≈180°)
#define DEAD_ROTATE_TIMEOUT_MS 4500UL  // максимум на разворот
#define DEAD_ROTATE_SPEED       70     // скорость разворота
#define WALL_FOLLOW_TIME_MS    6000UL  // время попытки движения вдоль стены
#define WALL_FOLLOW_TARGET_CM    20    // желаемое расстояние до стены
#define DEAD_ATTEMPT_LIMIT       3     // кол-во попыток вырваться перед SOS

// --- Состояние верификации тупика (НОВОЕ) ---
unsigned long deadVerifyStart = 0;
unsigned long deadRotateStart = 0;
unsigned long deadRotateLastMs = 0;
float         deadRotateYawAcc = 0.0f;   // накопленный yaw за время разворота
unsigned long wallFollowStart = 0;
uint8_t       deadAttempts = 0;           // сколько раз уже пытались выбраться
bool          wallFollowLeft = true;      // вдоль какой стены едем

// ── Одометрия и логирование ──────────────────────────────
// Скорость при SPEED_FULL: откалибруй один раз!
// Засеки время на 1 метр при PWM=200, раздели 1/время
#define SPEED_MPS       0.25f   // м/с при SPEED_FULL=200 (≈4 сек/метр)
#define CHECKPOINT_DIST  0.50f  // лог каждые 0.5 м
#define MIN_LOG_TURN    20.0f   // лог поворота если накопилось > 20°
#define LOG_PERIOD       500    // мс — период обновления одометрии

// ============================================================
//  КОНЕЧНЫЙ АВТОМАТ
// ============================================================
enum RobotState : uint8_t {
  ST_MANUAL,
  ST_AUTO_FWD,
  ST_AUTO_REVERSE,
  ST_AUTO_TURN,
  ST_AUTO_DEAD_VERIFY,   // НОВОЕ: отъезд назад перед проверкой
  ST_AUTO_DEAD_ROTATE,   // НОВОЕ: разворот на 180° для проверки тупика
  ST_AUTO_WALL_FOLLOW,   // НОВОЕ: движение вдоль стены
  ST_AUTO_DEAD,          // настоящий тупик (после всех проверок)
  ST_TILT_PAUSE,
  ST_TILT_TRY_MOVE
};
RobotState robotState = ST_MANUAL;

bool autoMode = false;

bool autoMissionActive = false;          // сейчас выполняется автономная миссия
bool autoMissionExpired = false;   // миссия завершилась по таймауту, повторно не запускать
unsigned long autoMissionStart = 0;      // старт миссии
unsigned long tiltPauseStart = 0;        // начало паузы из-за наклона
unsigned long tiltTryMoveStart = 0;      // старт короткой попытки движения
uint8_t tiltRetryCount = 0;              // число повторных попыток после опасного наклона
bool tiltPauseActive = false;            // активна пауза по наклону


// --- Фильтр наклона ---
uint8_t tiltBadCount = 0;
uint8_t tiltGoodCount = 0;
unsigned long tiltFirstBadMs = 0;

// --- Память препятствия ---
uint8_t repeatedObstacleCount = 0;
unsigned long lastObstacleMs = 0;

// --- Реверс перед разворотом ---
unsigned long reverseStartMs = 0;
bool reverseTurnToLeft = true;

// ============================================================
//  ОБЪЕКТЫ
// ============================================================
SoftwareSerial comSerial(SW_RX, SW_TX);
Servo camServo;

// ============================================================
//  UART
// ============================================================
char uartBuf[16];
uint8_t uartLen  = 0;
unsigned long lastHB = 0;
bool hbSeen = false;
bool clientConnected = false; // true = клиент подключён по Wi-Fi
bool recAutoSent = false;
char motorCmd    = 'S';

// ============================================================
//  СЕРВОПРИВОД
// ============================================================
int servoTarget = 90;
int scanAngle   = 90;
int scanDir     =  1;
unsigned long lastScan = 0;

// ============================================================
//  ЗУММЕР
// ============================================================
struct BuzzStep { uint16_t onMs; uint16_t offMs; };

const BuzzStep PAT_BEACON[] PROGMEM = { {100, 2000}, {0, 0} };
const BuzzStep PAT_SOS[]    PROGMEM = {
  {100,100},{100,100},{100,300},
  {300,100},{300,100},{300,300},
  {100,100},{100,100},{100,700},
  {0,0}
};

const BuzzStep PAT_ABANDONED[] PROGMEM = { {500, 20000}, {0, 0} };

enum BuzzMode : uint8_t { BM_OFF, BM_CONTINUOUS, BM_PATTERN };
BuzzMode buzzMode    = BM_OFF;
const BuzzStep* buzzPat = nullptr;
uint8_t  buzzIdx     = 0;
uint16_t buzzLoops   = 0;
uint16_t buzzMaxLoops = 0;
bool     buzzOnPhase = false;
unsigned long buzzTimer = 0;

// ============================================================
//  MPU6050
// ============================================================
float pitch    = 0.0f;
float gyroZ_dps = 0.0f;   // угловая скорость рыскания (°/с) — НОВОЕ
unsigned long lastIMU = 0;

// ============================================================
//  ДИСТАНЦИИ
// ============================================================
long dF = 200, dL = 200, dR = 200;
unsigned long lastDist = 0;



// ============================================================
//  ПОВОРОТ В АВТОПИЛОТЕ
// ============================================================
bool turnToLeft = true;

// ============================================================
//  ОДОМЕТРИЯ — НОВОЕ v2
// ============================================================
float  odo_distance    = 0.0f;  // пройдено, метры
float  odo_last_logged = 0.0f;  // расстояние последней записи в лог
float  yaw_accumulated = 0.0f;  // накопленный поворот с последней записи
unsigned long odo_last_ms = 0;  // время последнего обновления

int leftSpeed  = 0;  // текущие скорости (обновляются в setMotors)
int rightSpeed = 0;

// ============================================================
//  ЛОГИРОВАНИЕ — НОВОЕ v2
// ============================================================
enum LogEvent : uint8_t {
  EVT_CHECKPOINT,
  EVT_TURN,
  EVT_TILT,
  EVT_TILT_RESUME,
  EVT_OBSTACLE,
  EVT_DEAD_END,
  EVT_SIGNAL_LOST,
  EVT_SIGNAL_BACK,
  EVT_AUTO_START,
  EVT_AUTO_END
};

bool logSignalLostSent = false;  // чтобы не спамить при потере связи

void logEvent(LogEvent evt) {
  // Не спамим лог в ручном режиме — только важные события
  if (robotState == ST_MANUAL && 
      evt != EVT_AUTO_START && evt != EVT_AUTO_END) {
    return;
  }
  const char* evtName;
  switch (evt) {
    case EVT_CHECKPOINT:  evtName = "CHK";    break;
    case EVT_TURN:        evtName = "TURN";   break;
    case EVT_TILT:        evtName = "TILT";   break;
    case EVT_TILT_RESUME: evtName = "TRES";   break;
    case EVT_OBSTACLE:    evtName = "OBS";    break;
    case EVT_DEAD_END:    evtName = "DEAD";   break;
    case EVT_SIGNAL_LOST: evtName = "WLOST";  break;
    case EVT_SIGNAL_BACK: evtName = "WOK";    break;
    case EVT_AUTO_START:  evtName = "ASTART"; break;
    case EVT_AUTO_END:    evtName = "AEND";   break;
    default:              evtName = "UNK";    break;
  }

  char buf[64];
  int dist_cm   = (int)(odo_distance * 100);
  int yaw_x10   = (int)(yaw_accumulated * 10);
  int pitch_x10 = (int)(pitch * 10);

  snprintf(buf, sizeof(buf), "LOG:%s,%d,%d,%d,%ld,%ld,%ld\n",
           evtName, dist_cm, yaw_x10, pitch_x10, dF, dL, dR);

  comSerial.print(buf);

  yaw_accumulated = 0.0f;
  odo_last_logged = odo_distance;
}

// ============================================================
//  ОДОМЕТРИЯ: обновление (вызывать периодически) — НОВОЕ v2
// ============================================================
void updateOdometry() {
  unsigned long now = millis();
  if (now - odo_last_ms < (unsigned long)LOG_PERIOD) return;

  // Если только что был приём команды — подождём следующего цикла
  if (now - lastCmdTime < 50) return;

  float dt = (now - odo_last_ms) / 1000.0f;
  odo_last_ms = now;
  if (dt > 1.0f) { odo_last_ms = now; return; }  // защита от первого вызова

  // Текущая скорость по среднему PWM обоих моторов
  float avgPWM = 0.0f;
  if (robotState == ST_AUTO_FWD ||
      robotState == ST_AUTO_TURN ||
      robotState == ST_TILT_TRY_MOVE ||
      robotState == ST_MANUAL) {

    int lAbs = abs(leftSpeed);
    int rAbs = abs(rightSpeed);
    avgPWM = (float)(lAbs + rAbs) / 2.0f;
    // Считаем расстояние только при движении вперёд
    if (leftSpeed > 0 && rightSpeed > 0) {
      odo_distance += SPEED_MPS * (avgPWM / (float)SPEED_FULL) * dt;
    }
  }
  // В режиме спуска — скорость неизвестна (трос управляет), не считаем

  // Накопление рыскания из гироскопа
  yaw_accumulated += gyroZ_dps * dt;

  // ── Проверка триггеров логирования ───────────────────────
  if (odo_distance - odo_last_logged >= CHECKPOINT_DIST) {
    logEvent(EVT_CHECKPOINT);
  }
  if (fabsf(yaw_accumulated) >= MIN_LOG_TURN) {
    logEvent(EVT_TURN);
  }
}

// ============================================================
//  ВСПОМОГАТЕЛЬНАЯ: применить один мотор TB6612
// ============================================================
static void applyMotor(int spd,
                       uint8_t pin_in1, uint8_t pin_in2, uint8_t pin_pwm) {
  int s = constrain(abs(spd), 0, 255);
  if (spd > 0) {
    digitalWrite(pin_in1, HIGH); digitalWrite(pin_in2, LOW);
    analogWrite(pin_pwm, s);
  } else if (spd < 0) {
    digitalWrite(pin_in1, LOW); digitalWrite(pin_in2, HIGH);
    analogWrite(pin_pwm, s);
  } else {
    digitalWrite(pin_in1, LOW); digitalWrite(pin_in2, LOW);
    analogWrite(pin_pwm, 0);
  }
}

void setMotors(int left, int right) {
  // Сохраняем "идеальные" скорости для одометрии
  leftSpeed  = left;
  rightSpeed = right;

  // Аппаратная калибровка: направление и баланс
  int final_L = (int)(left  * MOTOR_L_SCALE * MOTOR_L_INVERT);
  int final_R = (int)(right * MOTOR_R_SCALE * MOTOR_R_INVERT);

  applyMotor(final_L, PIN_AIN1, PIN_AIN2, PIN_PWMA);
  applyMotor(final_R, PIN_BIN1, PIN_BIN2, PIN_PWMB);
}
void stopMotors() { setMotors(0, 0); }

// ============================================================
//  MPU6050: инициализация
// ============================================================
void mpuInit() {
  Wire.beginTransmission(MPU_ADDR);
  Wire.write(0x6B); Wire.write(0x00);
  Wire.endTransmission(true);

  Wire.beginTransmission(MPU_ADDR);
  Wire.write(0x1B); Wire.write(0x00);  // гироскоп ±250°/с
  Wire.endTransmission(true);

  Wire.beginTransmission(MPU_ADDR);
  Wire.write(0x1C); Wire.write(0x00);  // акселерометр ±2g
  Wire.endTransmission(true);

  lastIMU = millis();
}

// ============================================================
//  MPU6050: обновление тангажа + рыскания (комплементарный фильтр)
// ============================================================
void mpuUpdate() {
  Wire.beginTransmission(MPU_ADDR);
  Wire.write(0x3B);
  Wire.endTransmission(false);
  Wire.requestFrom((uint8_t)MPU_ADDR, (uint8_t)14, (uint8_t)true);

  int16_t rax = ((int16_t)Wire.read() << 8) | Wire.read();
  int16_t ray = ((int16_t)Wire.read() << 8) | Wire.read();
  int16_t raz = ((int16_t)Wire.read() << 8) | Wire.read();
  Wire.read(); Wire.read();            // температура — не нужна
  int16_t rgx = ((int16_t)Wire.read() << 8) | Wire.read();
  int16_t rgy = ((int16_t)Wire.read() << 8) | Wire.read();
  int16_t rgz = ((int16_t)Wire.read() << 8) | Wire.read();

  // Программный поворот осей под физическую установку датчика:
  // X робота вперёд = -Y сенсора, Y робота вправо = -X сенсора
  int16_t ax = -ray;
  int16_t ay = -rax;
  int16_t az = raz;
  int16_t gx = -rgy;
  int16_t gy = -rgx;
  int16_t gz = rgz;

  unsigned long now = millis();
  float dt = (float)(now - lastIMU) * 0.001f;
  if (dt <= 0.0f || dt > 0.5f) dt = 0.02f;
  lastIMU = now;

  // Тангаж (pitch) по акселерометру
  float aPitch = atan2f(-(float)ax,
                  sqrtf((float)ay * (float)ay + (float)az * (float)az))
                 * (180.0f / PI);

  // Угловая скорость тангажа
  float gRate = (float)gx / 131.0f;

  // Комплементарный фильтр тангажа
  pitch = 0.98f * (pitch + gRate * dt) + 0.02f * aPitch;

  // Угловая скорость рыскания (для одометрии)
  gyroZ_dps = (float)(GYRO_Z_INVERT * gz) / 131.0f;
}
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
void loop() {
  unsigned long now = millis();

  // ── 1. Приём команд от ESP32-CAM ───────────────────────────
  uartRead();

  // Отправляем REC_AUTO только после первого heartbeat от ESP32
  if (!recAutoSent && hbSeen) {
    comSerial.print("REC_AUTO\n");
    // Serial.print("REC_AUTO\n");
    recAutoSent = true;
  }

  // ── 2. Обновление тангажа + рыскания (IMU_PERIOD мс) ───────
  if (now - lastIMU >= IMU_PERIOD) {
    mpuUpdate();
  }

  // ── 3. Замер дистанций по одному датчику за раз ────────────
  static uint8_t sonarPhase = 0;
  if (now - lastDist >= (DIST_PERIOD / 3)) {
    lastDist = now;
    switch (sonarPhase) {
      case 0: dF = medDist(TRIG_F, ECHO_F); break;
      case 1: dL = medDist(TRIG_L, ECHO_L); break;
      case 2: dR = medDist(TRIG_R, ECHO_R); break;
    }
    sonarPhase = (sonarPhase + 1) % 3;
  }

  // ── 4. АБСОЛЮТНЫЙ ПРИОРИТЕТ: защита от спуска ──────────────
  if (robotState != ST_MANUAL) {
    checkTilt(now);
  }

  // ── 5. Одометрия и логирование маршрута — НОВОЕ ────────────
  if (robotState != ST_TILT_PAUSE) {
    updateOdometry();
  }

  // ── 6. Защита от потери оператора на долгое время ───────────


  // ── 7. Основная логика (если нет тревоги спуска) ───────────
  {
      bool hbTimedOut = (now - lastHB > MANUAL_FAILSAFE_TIMEOUT);

      // Если heartbeat вообще пропал (ESP32 отвалилась полностью) —
      // считаем клиента отключённым и запускаем автономную миссию
      if (hbTimedOut && clientConnected) {
          clientConnected = false;
          if (!logSignalLostSent) {
              logEvent(EVT_SIGNAL_LOST);
              logSignalLostSent = true;
          }
      }

      // Автопилот включается если:
      //  1) оператор явно нажал AUTO ('X')
      //  2) клиент отвалился (нет heartbeat или пришло 'A')
      //  3) уже идёт автономная миссия
      bool shouldAuto = (autoMode || !clientConnected || autoMissionActive || hbTimedOut) && !autoMissionExpired; 

      // Ручной режим ТОЛЬКО когда клиент живой и heartbeat свежий
      bool shouldManual = clientConnected && !hbTimedOut && !autoMode && !autoMissionActive && !autoMissionExpired;

      if (shouldAuto) {
          if (!autoMissionActive) {
              autoMissionActive = true;
              autoMissionStart = now;
              tiltRetryCount = 0;
              tiltPauseStart = 0;
              tiltTryMoveStart = 0;
              tiltPauseActive = false;
              tiltBadCount = 0;
              tiltGoodCount = 0;
              tiltFirstBadMs = 0;
              repeatedObstacleCount = 0;
              lastObstacleMs = 0;
              deadAttempts = 0;
              deadRotateYawAcc = 0.0f;  
              logEvent(EVT_AUTO_START);
          }

          // Ограничение миссии: 20 минут
          if (now - autoMissionStart >= AUTO_MISSION_TIME) {
              autoMissionActive = false;
              autoMode = false;
              autoMissionExpired = true;
              robotState = ST_AUTO_DEAD;
              stopMotors();
              buzzPattern(PAT_ABANDONED, 20);
              logEvent(EVT_AUTO_END);
          } else {
              if (robotState == ST_MANUAL) {
                  robotState = ST_AUTO_FWD;
                  buzzPattern(PAT_BEACON, 1);
              } else if (robotState != ST_AUTO_FWD &&
                        robotState != ST_AUTO_REVERSE &&
                        robotState != ST_AUTO_TURN &&
                        robotState != ST_AUTO_DEAD_VERIFY &&
                        robotState != ST_AUTO_DEAD_ROTATE &&
                        robotState != ST_AUTO_WALL_FOLLOW &&
                        robotState != ST_AUTO_DEAD &&
                        robotState != ST_TILT_PAUSE &&
                        robotState != ST_TILT_TRY_MOVE) {
                  robotState = ST_AUTO_FWD;
              }

          }
      } else if (shouldManual) {
          if (robotState != ST_MANUAL) {
              robotState = ST_MANUAL;
              autoMissionActive = false;
              tiltPauseActive = false;
              tiltPauseStart = 0;
              tiltTryMoveStart = 0;
              tiltRetryCount = 0;
              tiltBadCount = 0;
              tiltGoodCount = 0;
              tiltFirstBadMs = 0;
              repeatedObstacleCount = 0;
              lastObstacleMs = 0;
              deadAttempts = 0;              // НОВОЕ
              deadRotateYawAcc = 0.0f;       // НОВОЕ
              stopMotors();
              buzzOff();
              logEvent(EVT_AUTO_END);
          }
      }
      // УБИРАЕМ ветку else со stopMotors() — теперь она не нужна,
      // потому что shouldAuto покрывает случай потери связи

      // ── Выполнение ───────────────────────────────

      switch (robotState) {
          case ST_MANUAL:            handleManual();              break;
          case ST_AUTO_FWD:          handleAutoFwd();             break;
          case ST_AUTO_REVERSE:      handleAutoReverse(now);      break;
          case ST_AUTO_TURN:         handleAutoTurn();            break;
          case ST_AUTO_DEAD_VERIFY:  handleAutoDeadVerify(now);   break;  // НОВОЕ
          case ST_AUTO_DEAD_ROTATE:  handleAutoDeadRotate(now);   break;  // НОВОЕ
          case ST_AUTO_WALL_FOLLOW:  handleAutoWallFollow(now);   break;  // НОВОЕ
          case ST_AUTO_DEAD:         handleAutoDead();            break;
          case ST_TILT_PAUSE:        handleTiltPause(now);        break;
          case ST_TILT_TRY_MOVE:     handleTiltTryMove(now);      break;
          default: break;
      }

      if (robotState != ST_MANUAL) {
          updateScan(now);
      }
  }

  // ── 8. Обновление зуммера ───────────────────────────────────
  buzzUpdate();
}

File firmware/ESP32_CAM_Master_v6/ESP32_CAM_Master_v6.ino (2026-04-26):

/*
 * ============================================================
 *  ESP32_CAM_Master.ino  — v2.0
 *  Робот-телеинспектор вентиляции — Мастер (ESP32-CAM AI-Thinker)
 *
 *  НОВОЕ в v2.0:
 *    • Автостарт записи видео при включении (не надо жать REC)
 *    • Приём LOG:-строк от Arduino по UART → запись в route_log.csv
 *    • Команда REC_AUTO от Arduino → запуск сессии
 *    • Отображение расстояния и состояния в веб-интерфейсе
 *
 *  Функции:
 *    • Wi-Fi точка доступа "Crawler_Inspector" / "crawler123"
 *    • Веб-интерфейс (порт 80): MJPEG-видео + джойстик + серво
 *    • MJPEG-поток (порт 81): для iframe/img в браузере
 *    • Запись JPEG-кадров на SD-карту (папки /REC_<n>)
 *    • Лог маршрута: /route_log.csv на SD (новое v2)
 *    • Отправка команд и хартбита по UART0 → Arduino UNO
 *
 *  Подключение UART0:
 *    ESP32 GPIO1 (TX) → TXS0108E A1 → B1 → Arduino pin 10 (RX)
 *    ESP32 GPIO3 (RX) → TXS0108E A2 → B2 → Arduino pin 11 (TX)
 *    TXS0108E VCCA = 3.3V,  VCCB = 5V,  OE = 3.3V
 *
 *  ⚠ После загрузки прошивки через MB-плату
 *    ОТКЛЮЧИТЕ USB-кабель, затем подключайте Arduino к UART.
 *    Иначе Arduino будет "слышать" USB-мусор.
 *
 *  Зависимости (установить через Boards Manager):
 *    • "ESP32 by Espressif Systems" ≥ 2.0
 * ============================================================
 */

#include "esp_camera.h"
#include "esp_timer.h"
#include "Arduino.h"
#include "soc/soc.h"
#include "soc/rtc_cntl_reg.h"
#include "esp_http_server.h"
#include <WiFi.h>
#include "FS.h"
#include "SD_MMC.h"

// ============================================================
//  ПИНЫ КАМЕРЫ (AI-THINKER ESP32-CAM)
// ============================================================
#define PWDN_GPIO_NUM    32
#define RESET_GPIO_NUM   -1
#define XCLK_GPIO_NUM     0
#define SIOD_GPIO_NUM    26
#define SIOC_GPIO_NUM    27
#define Y9_GPIO_NUM      35
#define Y8_GPIO_NUM      34
#define Y7_GPIO_NUM      39
#define Y6_GPIO_NUM      36
#define Y5_GPIO_NUM      21
#define Y4_GPIO_NUM      19
#define Y3_GPIO_NUM      18
#define Y2_GPIO_NUM       5
#define VSYNC_GPIO_NUM   25
#define HREF_GPIO_NUM    23
#define PCLK_GPIO_NUM    22

// ============================================================
//  НАСТРОЙКИ
// ============================================================
const char* AP_SSID        = "Crawler_Inspector";
const char* AP_PASS        = "crawler123";
const IPAddress AP_IP(192, 168, 4, 1);
const IPAddress AP_GW(192, 168, 4, 1);
const IPAddress AP_SN(255, 255, 255, 0);

#define UART_BAUD          9600
#define HEARTBEAT_MS        500
#define FRAME_SAVE_MS       500   // 2 fps
#define CMD_REPEAT_MS       120

// MJPEG
#define PART_BOUNDARY      "frame"
static const char* STREAM_CT  =
  "multipart/x-mixed-replace;boundary=" PART_BOUNDARY;
static const char* STREAM_SEP =
  "\r\n--" PART_BOUNDARY "\r\n";
static const char* STREAM_HDR =
  "Content-Type: image/jpeg\r\nContent-Length: %u\r\n\r\n";

// ============================================================
//  СОСТОЯНИЕ
// ============================================================
bool       isRecording  = false;
volatile int activeStreams = 0;
bool       recLocked    = true;
bool       sdOK         = false;
char       motorCmd     = 'S';
int        servoAngle   = 90;
int        frameNum     = 0;
String     sessionDir   = "";
String     logFilePath  = "";

bool autoMode = false;

unsigned long lastHB        = 0;
unsigned long lastFrameSave = 0;
unsigned long lastCmdSend   = 0;

// Состояние для отображения в веб-интерфейсе — НОВОЕ
char   crawlerStatus[32] = "READY";   // текущее состояние
char   lastLogLine[80]   = "";        // последняя строка лога

// Буфер входящих данных от Arduino — НОВОЕ
#define UART_RX_BUF 128
char   uartRxBuf[UART_RX_BUF];
uint8_t uartRxLen = 0;

// ============================================================
//  HTTP СЕРВЕРЫ
// ============================================================
httpd_handle_t webSrv    = NULL;
httpd_handle_t streamSrv = NULL;

// ============================================================
//  HTML/JS СТРАНИЦА (встроена во Flash)
// ============================================================
static const char INDEX_HTML[] = R"rawliteral(
<!DOCTYPE html>
<html lang="ru">
<head>
<meta charset="UTF-8">
<meta name="viewport" content="width=device-width,initial-scale=1,maximum-scale=1,user-scalable=no">
<title>Crawler Inspector</title>
<style>
#autoBtn{
  padding:7px 14px;
  background:#30363d;
  color:#fff;
  border:none;
  border-radius:6px;
  cursor:pointer;
  font-size:.85em;
  font-weight:600;
}
#autoBtn.active{
  background:#f85149;
}

*{box-sizing:border-box;margin:0;padding:0;-webkit-tap-highlight-color:transparent}
body{background:#0d1117;color:#c9d1d9;font-family:'Segoe UI',Arial,sans-serif;
     display:flex;flex-direction:column;align-items:center;min-height:100vh;padding:8px;gap:8px}
h1{color:#58a6ff;font-size:1.1em;letter-spacing:3px;padding:6px 0}
#statusBar{font-size:.75em;color:#8b949e;height:16px}
#vidBox{width:100%;max-width:640px;background:#000;border:2px solid #21262d;border-radius:8px;overflow:hidden;position:relative}
#vidBox img{width:100%;display:block}
.overlay{position:absolute;top:6px;right:8px;background:rgba(0,0,0,.6);
          border-radius:4px;padding:2px 6px;font-size:.7em;color:#f85149;
          display:none}
.overlay.show{display:block;animation:blink 1s step-start infinite}
@keyframes blink{50%{opacity:0}}
.row{display:flex;gap:16px;align-items:flex-start;flex-wrap:wrap;justify-content:center;width:100%;max-width:640px}
#joyWrap{display:flex;flex-direction:column;align-items:center;gap:4px}
#joyWrap span{font-size:.75em;color:#8b949e}
#joyCanvas{cursor:pointer;touch-action:none;border-radius:50%;
           background:radial-gradient(circle at 40% 35%,#1c2128,#0d1117);
           border:2px solid #21262d}
.servoPanel{display:flex;flex-direction:column;align-items:center;gap:6px;min-width:80px}
.servoPanel label{font-size:.75em;color:#8b949e;text-align:center}
#servoSlider{
  -webkit-appearance:slider-vertical;
  writing-mode:vertical-lr;direction:rtl;
  height:140px;width:28px;
  accent-color:#58a6ff;cursor:pointer
}
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
